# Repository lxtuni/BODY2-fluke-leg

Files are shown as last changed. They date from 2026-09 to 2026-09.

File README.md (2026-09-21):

# BODY2-fluke-leg — Paddling leg for the amphibious quadruped BODY2: fluke-foot design, hydrodynamics and servo trajectory

## Layout

| Folder | Content | Entry point |
|---|---|---|
| `cad/` | One-piece straight fluke foot **A2** (single PETG print: mounting tab → strut → filament-pin hinge + leaf springs → lunate fluke); STL/STEP output, size check, hull cross-section | `fluke_straight_cad.py` generates the part; `直排一体件A2_说明.md` print/assembly notes |
| `firmware/` | Sculling swim trajectory for the motion-control team: `scull_gait_patch.c` (replaces `swim_leg_pose()`), 100-points-per-cycle CSV, servo-angle check | `README_scull.md` |
| `hydro/` | Fluke hydrodynamics: UVLM flapping-foil solver, passive-pitch FSI (phasor method), sculling FSI, E-pivot spade paddle, area/aspect-ratio sweeps | `uvlm_foil.py` (solver) → `passive_pitch.py` / `sculling_fsi.py` |
| `cfd/` | Case generation and post-processing for OpenFOAM overset single-leg / full-robot unsteady CFD (`overPimpleDyMFoam` + `tabulated6DoFMotion`) | `README_cfd.md`, `make_leg_cfd.py`, `paddle_forces.py`, `run_cloud.sh` |
| `gait/` | Optimal-stroke theory for drag-based paddling, fold-timing sweep, structure-independent target trajectory, CFD-matrix post-processing | `optimal_trajectory.py`, `fold_timing_sweep.py`, `gait_to_firmware.py` |
| `docs/` | Research notes 00–14 (chronological, with design decisions), reference list `.bib`, key figures | `docs/notes/00_阅读顺序.md` |

## Current design status (2026-09-20)
- **Mechanism**: leg hangs down, long link stays vertical, the stem swings about the hip axis through **−18° ± 18°** (horizontal at the top of the stroke); the fluke pitches passively on a pin hinge at the stem tip (leaf-spring restoring stiffness k ≈ 2.5 mN·m/rad).
- **Fluke**: lunate planform, AR 3.1, span 60 mm, 11.5 cm², NACA 0021; whole part 98 × 11 × 60 mm, 6.9 g PETG. The 86 mm-span A1 hit the hull bottom at the top of the stroke and was dropped (`docs/figures/fig_size_check.png`).
- **Thrust estimate** (UVLM upper bound × 0.7): ≈ 20 mN per paddle at 1.5 Hz, ≈ 35 mN at 2 Hz. To be measured in the tank.
- **Ballast**: waterline at the hull top; water depth ≥ 15 cm.

## Environment
```bash
pip install -r requirements.txt
# CFD needs OpenFOAM v2606 (WSL2/Ubuntu), see cfd/README_cfd.md
# gait/ post-processing reads local CFD results: export BODY2_CFD_RESULTS=/path/to/leg_dynamics
```

## Reproducing the main results
```bash
python cad/fluke_straight_cad.py          # → cad/fluke_straight_A2.stl/.step + stiffness/strain JSON
python firmware/scull_trajectory.py       # → trajectory CSV + C patch + servo-angle ranges
python hydro/sculling_fsi.py              # sculling FSI sweep (f, θs0, k); takes tens of minutes
python cad/fig_size_check.py              # hull cross-section vs fluke envelope (needs hull_only.step, extracted from the assembly STEP, not tracked)
```

## Not tracked
CFD cases and results (`results_leg/`, `results_verify/`, several GB), animation frames, `.docx/.pdf` reports, SolidWorks sources and the full-robot assembly STEP.

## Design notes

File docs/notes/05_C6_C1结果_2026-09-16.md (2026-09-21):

# 05 · C6 + C1 结果（2026‑09‑16，april 本机 8 核，4 次计算共 3.4 h）

数据：`results_verify/V3c12 V3c06 V3trap`（closed‑only 方案配 V3 的 open）；两态合成第 3 周期；图 `fig_fold_timing_sweep.png`、`results_verify/fig_verify.png`。

| 方案 | 收拢宽 | 速度律 | T / DUTY | F̄x [mN] | 划水 / 回收贡献 | 每周期冲量 [mN·s] | F̄z | \|M_y\| 峰 [mN·m] | P̄ [mW] | F̄x/P̄ |
|---|---|---|---|---|---|---|---|---|---|---|
| V3 | 30 mm | 余弦 | 0.81 / 0.45 | 49.3 | +60.0 / −10.7 | 40.0 | 13.7 | 19.3 | 16.2 | 3.05 |
| V3c12 | 12 mm | 余弦 | 0.81 / 0.45 | **56.7** (+15 %) | +60.0 / −3.2 | 46.0 | 9.9 | 19.3 | 13.7 | 4.13 |
| V3c06 | 5.6 mm（羽化） | 余弦 | 0.81 / 0.45 | 58.6 (+3 % vs c12) | +60.0 / −1.4 | 47.4 | 9.1 | 19.3 | 13.1 | 4.46 |
| V3trap | 12 mm | 梯形 45 ms 斜坡 | 0.72 / 0.382 | **75.0** (+32 % vs c12) | +79.5 / −4.4 | 54.0 (+18 %) | 13.9 | **35.6** | 20.8 | 3.61 |

## 结论
1. **C6 收拢宽度**：30 → 12 mm 使回收阻力从 −10.7 降到 −3.2 mN（÷3.3），周期平均 +15 %，F̄z 也降 28 %。closed‑only 周期平均 21.0 → 4.8 → 1.9 mN。有效阻力比 a（closed/open 周期平均）0.48 → 0.11 → 0.04。
2. **羽化（5.6 mm）只再多 +1.9 mN（+3 %）**。深挖后修正原因：回收阻力其实与宽度成正比（0.70 mN/mm，截距 ≈ 0，杆/附加质量不是地板），但 12 mm 时回收拖累只剩周期平均的 6 %，羽化最多再拿回其中一半。**羽化机构不做**；把收拢宽做到 ≤ 12 mm 即可。
3. **C1 梯形速度律**：划水冲量 48.6 → 57.2 mN·s（+18 %），周期平均 +32 %（含周期缩短 0.81 → 0.72）。深挖后修正解释：同峰值速率、同 50° 摆角下准定常 ∫v² 本来就只多 18 %，CFD 与之一致；有效 C_N（起动 ≈ 5 → 1.5 弦后 2.5–4）在两种速度律下相同，**并没有被恒速段衰减掉**。理论文档的 +60–70 % 隐含“同一划水时间扫 1.33 倍的角”，即要加大摆角/行程 → C2。代价：|M_y| 峰值 19.3 → 35.6 mN·m（×1.84），F_x 峰 277 → 474 mN，P̄ +52 %，F̄x/P̄ 从 4.13 降到 3.61。**目标是最大推力 → 采用梯形**；若舵机峰值力矩 < 40 mN·m 或电源受限，把斜坡放宽到 60–70 ms 折中。
4. **开合时刻（fold_timing_sweep 一维 + deep_dive_optimal 二维）**：二维最优 τ_o −0.06 / τ_c 0.33（V3trap，+16 % → 87.2 mN；V3c12 τ_c 0.37，+12 % → 63.5 mN）。一维结论：三个新方案最优收扇都在 τ_c ≈ 0.86–0.87 × DUTY（V3c12 0.37、V3trap 0.33），即划水减速开始处，与 04 的目标轨迹一致；提前收扇的收益随回收阻力变小反而变大（V3trap +7.5 mN/0.05 T，早收 → 82.7 mN），晚收代价 −4.9 mN/0.05 T。开扇最优 τ_o ≈ −0.06（回收减速起点），+3–6 %。合成上限：V3trap 早收 + 早开 ≈ 85 mN（现 V3 49.3 的 1.7 倍）。

## 对目标轨迹（04）的更新
- 收拢宽度 12 mm、不羽化；DUTY* 按 a = 0.11 重算：x* = √(1+1/a) − 1 = 2.18 → DUTY* = 0.69（准定常极限，说明回收可以更慢；实际取 0.42–0.45 受舵机回收速度限制而不是阻力）。
- 速度律：梯形，v_max 0.35 m/s，斜坡 45 ms（若力矩允许）。
- 收扇 = 划水减速起点，开扇 = 回收减速起点，均不变。

## 深挖产物（2026‑09‑16 下午）
`deep_dive_optimal.py` → `fig_dd_timeseries / unsteady / recovery / timing_map / waterfall.png`、`deep_dive_optimal.json`；`make_optimal_anim.py` → `optimal_gait_cfd_anim.mp4`（放慢 5×，2 周期）+ 分镜；`make_optimal_report.js` → `results/BODY2_最优轨迹报告_2026-09-16.pdf/.docx`（8 页）。最优轨迹定义见报告表 3 / 表 4：V3trap + 收扇 τ 0.33（238 ms，划水减速起点）+ 开扇 τ −0.06（677 ms，回收减速起点）→ F̄x 87.2 mN、冲量 62.8 mN·s、|M_y| 峰 36.7 mN·m、P̄ 21.4 mW。

## 下一步（C2 行程长度）
`ORDER="opt optL63 optL126" NP=8 nohup bash run_cloud.sh > ~/run/run_cloud2.out 2>&1 &`（6 次，约 5–6 h）：决定行程 1.5 / 2 / 3 弦，同时 opt 是整条目标轨迹 vs V3trap 的正面验证。之前须确认舵机峰值力矩 ≥ 40 mN·m（0.4 kg·cm，几乎所有舵机都满足）。

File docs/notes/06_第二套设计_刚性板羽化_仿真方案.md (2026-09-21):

# 06 · 第二套设计：刚性板 + 脚踝羽化关节 —— 仿真方案（2026‑09‑16）

## 0. 设计定义（Design 2）

- 桨板 Paddle：刚性矩形板，厚 5.6 mm，长 42 mm（沿桨杆），宽默认 **44 mm**（等面积 = 18.5 cm²，与第一套 120° 折扇正对面积相同，可直接对比）；变体 73 mm（30.7 cm²，= 折扇最宽处）。
- 脚踝 Knöchel：**主动舵机**，只有两个位置。绕桨杆轴（feathering axis）转 β：划水 β = 0（板面 ⟂ x，正对来流），回程 β = 90°（板面与 x–z 面共面，对面内任何运动都是最小截面 5.6 × 42 = 2.4 cm²，13 %；折扇收拢 12 mm 是 5.0 cm²，27 %）。
- 髋 Hüfte：形式不限，只要求走**结构无关的目标轨迹**（04：直线 84 mm，z = −85 mm，v_max 0.35 m/s，斜坡 45 ms，停顿 30 ms，抬升 30 mm，T 0.684 s，DUTY 0.416）。
- 不再仿真折扇的两态拼接：板绕自身轴的旋转 β(t) 直接写进 6DoF 表（rx ry rz 三个欧拉角），**一次算例含整周期**。

## 1. 生成器改动（make_leg_cfd.py）

```
--fan plate                 # 矩形板（与 open/closed 并列）
--plate-w 0.044             # 板宽 [m]；0.073 = 折扇最宽
--plate-l                   # 板长，默认 HEAD 42 mm
--feather TC,TO,TF[,lin]    # 羽化：收指令相位 τ_c、展开指令相位 τ_o、过渡时间 TF [s]
                            # 缺省余弦斜坡；lin = 匀速（限速舵机）；例 0.351,-0.066,0.11,lin
```
- 6DoF.dat 行：`(t ((tx 0 tz) (rx ry rz)))`，欧拉角 = scipy 'XYZ'（= OpenFOAM `quaternion::XYZ`），已 unwrap。
- 运动包络 (overset 背景加密区) 已按 β 旋转板角点重新计算。
- `kinematics_check.csv` 多出 `beta_deg,rx,ry,rz`；`gait.json` 记录 FEATHER / PLATE_W / PLATE_L。
- 已验证几何：沿桨杆 92 mm；板法向 / 横向尺寸在 β = 0 → 90° 之间 5.6 ↔ 44 mm 互换。

`compare_verify.py` 识别标签 `plate`（模式 `plate_single`，无拼接，直接取第 3 周期均值）。

## 2. 算例表（run_cloud.sh，ORDER 顺序）

| 算例 | 轨迹 | 板宽 | 羽化 (τ_c, τ_o, TF) | 回答的问题 |
|---|---|---|---|---|
| D2a | V3trap（第一套的髋轨迹） | 44 | 0.33, −0.06, 40 ms | 同轨迹、同面积：刚性板+羽化 vs 折扇最优 87.2 mN → 只看"回程截面"的价值 |
| D2b | 04 目标轨迹（直线） | 44 | 0.351, −0.066, 40 ms | 第二套的**基准**：结构无关轨迹 + 快舵机 |
| **D2s** | 04 | 44 | TF 110 ms，匀速 (lin) | **实际舵机 7465W @8.4 V**（0.07 s/60° → 857 °/s，带载 ≈ 820 °/s） |
| D2c100 | 04 | 44 | TF 100 ms（cos） | 舵机 900 °/s 均速的损失 |
| D2c200 | 04 | 44 | TF 200 ms | 舵机 450 °/s（普通 9 g 舵机）的损失 → 选型曲线 |
| D2w73 | 04 | 73 | 40 ms | 面积 +66 % 换推力的代价（功率、侧向力、回程阻力） |
| D2nof | 04 | 44 | 无羽化 | 对照：不转板，回程正对 → 羽化本身的收益 |

预计 NP = 8 每例 55–70 min，七例 ≈ 7–8 h（D2c100 与 D2s 接近，可省）。

`--feather` 第 4 项 `lin` = 匀速斜坡（限速舵机真实形状，峰值速率 = 均速）；缺省 `cos` 的峰值速率是均速的 1.57×，对限速舵机偏乐观。

WSL（在 leg_dynamics 目录）：
```
ORDER="D2b D2s D2nof D2a D2c200 D2w73" NP=8 nohup bash run_cloud.sh > ~/run/run_cloud_d2.out 2>&1 &
tail -f ~/run/run_cloud_d2.out
```

## 3. 预期与判据

- D2b vs 折扇最优 87.2 mN：板正对面积相同，划水段应接近（±10 %，板的 C_N 略高于扇因为无缝隙）；回程阻力应从折扇最优 ≈ −6 mN 降到 ≈ −2 mN → 净推力 ≈ +5 %，主要收益在**回程功率**和横向力，而非净推力。
- D2c100 / D2c200：损失 = 板在划水减速段（τ 0.35–0.42）和回程加速段仍是斜的；预计 100 ms ≈ −3 %，200 ms ≈ −10 %（斜板在 v ≈ 0.2 m/s 下产生升力式侧向力，还会带来 M_y）。
- D2w73：推力上限 ≈ ×1.5，功率 ×1.7，若 F̄z/F̄x 或 |M_y| 明显恶化则不值得。
- D2nof：预期净推力比 D2b 低 30–40 % —— 羽化关节必要性的直接证据。

## 4. 选定舵机：7465W（防水，12 g，金属齿轮，空心杯，180°）

| 电压 | 空载速度 | 堵转力矩 | 空载 / 堵转电流 |
|---|---|---|---|
| 5.0 V | 0.110 s/60° | 3.8 kg·cm | 46 mA / 1.0 A |
| 6.0 V | 0.092 s/60° | 4.5 kg·cm | 53 mA / 1.15 A |
| 7.4 V | 0.075 s/60° | 5.5 kg·cm | 56 mA / 1.4 A |
| **8.4 V** | **0.070 s/60°** | **5.8 kg·cm** | 63 mA / 1.6 A |

按 8.4 V 档：
- 脚踝：857 °/s 空载 → 90° 需 105 ms；羽化水动力矩峰值 ≈ 40 mN·m = 0.4 kg·cm，仅 7 % 堵转 → 速度降 ≈ 7 % → **90° ≈ 110 ms（算例 D2s）**。落在 D2c100 附近，比 40 ms 基准慢 2.7×，预计损失 3–5 %。
- 髋（若同型号，转动关节，杆长 L ≈ 0.12 m）：v_max 0.35 m/s → 167 °/s，仅用到速度的 20 %；峰值水动力矩 ≈ 0.5 N × 0.12 m = 60 mN·m = 0.6 kg·cm（10 % 堵转）+ 板/舵机惯性，余量充足。髋是直线机构则另算。
- 功率（电）：每个舵机运动时 ≈ 8.4 V × (63 mA + 负载电流) ≈ 0.6–1 W，远大于水动力功率 21 mW → 效率由舵机决定，不由水动力决定；四条腿 8 个舵机 ≈ 5–8 W。
- 质量：12 g 在脚踝处（水下有效 ≈ 12 g − 排水 ≈ 4 g 浮力）→ 髋要多承 ~0.1 N 的静力矩，可忽略。

## 4b. 旧估算（保留对照）

- 脚踝：90° 在 40 ms → 2250 °/s（0.027 s/60°）；100 ms → 900 °/s；普通 9 g 舵机 ≈ 500 °/s → 180 ms。力矩峰值 ≈ 40 mN·m = 0.4 kg·cm（任何舵机都够）。**瓶颈是速度**。
- 髋：v_max 0.35 m/s、斜坡 45 ms、峰值横向力 ≈ 0.5 N；若髋是转动关节且杆长 L，则 ψ̇_max = 0.35/L。
- 若买不到 ≥ 1000 °/s 微型舵机：改被动风向标式羽化（自由铰 + 限位），减速段松开靠水流翻转——需要另一组算例（板绕轴的自由转动，6DoF 求解而非表驱动）。

待确认：髋是否同型号 7465W、髋关节形式（转动杆长 / 直线）。

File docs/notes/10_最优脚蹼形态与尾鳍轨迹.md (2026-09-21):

---
title: 10 · 最优脚蹼形态与最佳尾鳍轨迹（UVLM 优化，U = 0.25 m/s）
date: 2026-09-18
status: result
---

# 10 · 最优脚蹼形态与最佳尾鳍轨迹

**问题**：U = 0.25 m/s 巡航，脚蹼面积固定 18.5 cm²，f ≤ 3 Hz，沉浮半幅 h₀ ≤ 50 mm，α_max ≤ 30°；腿做流线型、不考虑舵机。求单桨周期平均推力最大的形态和轨迹。
**方法**：三维非定常涡格法 UVLM（PteraSoftware 5.1），684 次计算（几何 120 + 运动学 564），每次 4–6 s。黏性用 Floryan 2017 式常数偏置 C_D = 0.03。
**产物**：`fig_fluke_optimum.png/.pdf`、`fluke_optimum_anim.mp4`、`fluke_AR4_t0.5_s35.stl`（可打印）、`*_planform_mm.csv`、`*_section_NACA0021.csv`、`sweep_A/B/C.csv`、脚本 `uvlm_foil.py / sweep_fluke.py / fluke_design.py / fig_fluke_optimum.py / make_fluke_opt_anim.py`。

## 一、答案

### 形态（脚部）

| 项 | 取值 | 依据 |
|---|---|---|
| 平面形 | **月牙形（lunate）**：前后缘同时后掠 35°，翼尖弦/展中弦 = 0.5 | 五族平面形里推力最高（比矩形 +3–8%）、效率最高 |
| 展弦比 | **AR 4**（展 86 mm，展中弦 28.7 mm，翼尖弦 14.3 mm） | UVLM 里推力随 AR 单调升（AR 2→6：+47%），但黏性文献（Lagopoulos 2023，Re 8500）C_T 到 AR 4 饱和；再高弦太短、Re 掉 |
| 截面 | **NACA 0021**：t_max 21% @ 0.30c，前缘 R 1.4 mm，尾缘闭合 | Kelly 2023 在 Re 10⁴ 的最优（0.21c @ 0.30c）= 海豚尾鳍实测（0.218c @ 0.285c）；UVLM 不含截面，这一条直接采用文献 |
| 俯仰轴 / 支杆 | **0.30–0.35 c**（展中弦前缘后 8.6–10 mm） | 0.4c 比 0.2c 多 2% 推力，差别小；取 1/3 与文献一致 |
| 支杆 | 流线型截面，尽量短，接在展中 | 见 09 号审查 #4 |

### 轨迹（尾鳍运动）

三条共同结论，对所有 f、h₀ 都成立：

1. **ψ = 90°**（俯仰领先沉浮 1/4 周期）。75° 和 105° 在 St > 0.5 时正弦俯仰压不住攻角上限，且推力低一半。
2. **攻角顶到上限 30°**。α_max 从 20° → 30°，推力 ×2.2。羽化幅值 θ₀ 由 α 上限反解。
3. **推力随 St 单调增长到约 1.0**，之后被 θ₀ 卡住（St 1.2 要 θ₀ = 66°）。

| 工况 | f | h₀ | θ₀ | ψ | St | 推力/桨 | 功率 | η | 俯仰峰速 |
|---|---|---|---|---|---|---|---|---|---|
| **上界（约束盒角）** | 3.0 Hz | 50 mm | 66° | 90° | 1.20 | **346 mN** | 125 mW | 0.69 | 1246 °/s |
| **可信最优（St ≤ 0.8）** | 2.0 Hz | 50 mm | 44° | 90° | 0.80 | **260 mN** | 98 mW | 0.66 | 554 °/s |
| 高效点 | 2.5 Hz | 30 mm | 48° | 90° | 0.60 | 102 mN | 29 mW | 0.87 | 747 °/s |

**推荐用"可信最优"**：St 0.8 已在验证范围（Read 2003 到 St 0.6）附近，无黏上偏可控在 ~20%；St 1.2 的 346 mN 是无失速模型的上界，真实值大概率低得多。

## 二、这个数意味着什么

整机阻力（腿整流后）21–36 mN，四桨只需每桨 **5–9 mN**。可信最优给 260 mN/桨 —— **推力富余 30 倍**。所以：

- U = 0.25 m/s 不是极限，是下限。按推力 ∝ U² 粗算，四桨 1 N 推力对应的自航速度在 0.8–1.2 m/s 量级（受 Re、自由面、舵机三重限制，实际会低）。
- 真正的设计问题不是"够不够推力"，而是**"在推力富余 30 倍的情况下，把 f、h₀ 降到哪里最省电"** —— 那就是高效点那条线（η 0.87，29 mW 出 102 mN，仍是需求的 11 倍）。

## 三、方法与可信度

**验证**（`uvlm_validation.md`）：Schouveiler 2005（Re 4×10⁴，St 0.25，α 15°）：UVLM C_T 0.354 vs 实验 0.32 ± 0.01，η 0.75 vs 0.73 ± 0.04；加 C_D 0.01–0.03 后落进误差棒。Read 2003 最大推力点（St 0.6，α 35°）：C_T 2.96 vs 2.4（**+23%，失速缺失**）。网格/时间步/自由尾迹/周期数敏感性 ≤ 4%。

**不可信的地方**（必须由 LES 复核）：
- α_max = 30° 处推力上偏 ~20%；St > 0.8 的点当上界。
- ψ = 75° 且强羽化的 30 个算例无黏 η > 0.9（功率账不闭合），已剔除。
- St 1.2 的 α 时程呈双峰带缺口（正弦俯仰在大羽化下的固有形状，见视频下图），LEV 会在冲程中间脱落 —— 这正是 09 号里说的"高 St 要做 α 波形整形"，UVLM 看不见这一点。
- 平面形效应 UVLM 只给 3–8%，黏性文献给 15–45%（Van Buren 2017、Fernández-Gutiérrez 2021）；月牙 + 前窄后宽的方向两边一致，量以 LES 为准。
- AR 4 时展中 Re ≈ 7×10³–10⁴，翼尖只有一半；Re 惩罚只用 C_D 0.03 粗算了。

## 四、下一步（按 09 号三层法）

1. LES 复核两个点：可信最优（St 0.8）和高效点（St 0.6），带支杆、NACA 0021、月牙 AR 4 → 校准 UVLM 的 C_D 偏置和 α 上偏。
2. 在 LES 校准后的 UVLM 上做 α 波形整形（方波/前载）扫描 —— St 0.8 处有可能再拿 10–30%。
3. 整机：船体 + 整流腿 RANS 定阻力曲线；两桨串列相位。

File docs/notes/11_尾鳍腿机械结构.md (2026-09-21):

---
title: 11 · 尾鳍腿的机械结构：双连杆可行吗，最优结构是什么
date: 2026-09-18
status: proposal
---

# 11 · 尾鳍腿的机械结构

配套：`mechanism_anim.mp4`（8 s，放慢 2×，含舵机位置）、`fig_mechanism_frame.png`、脚本 `make_mechanism_anim.py`。

## 一、双连杆可不可行 —— 可行，但第二连杆必须是脚蹼本身

尾鳍轨迹需要两个独立量：**位置（沉浮）** 和 **姿态（俯仰，且领先 90°）**。

| 结构 | 自由度 | 能否做尾鳍轨迹 |
|---|---|---|
| 髋 + 膝（两个位置自由度，脚蹼固连在小腿上） | 2 | **不能**。位置定了姿态就定了，做不出"位置和姿态各走各的正弦、相差 90°" |
| 髋 + 脚蹼俯仰（摇臂 + 攻角） | 2 | **能**。沉浮走弧线而不是直线，但这没关系（下） |
| 髋 + 膝 + 脚蹼俯仰 | 3 | 能，且能走直线沉浮 —— 但多出来的膝没有收益 |

**膝关节没有必要 —— UVLM 算过**：腿长 110 mm 的摇臂弧线沉浮（髋摆 ±27°，附带 ±6 mm 的 2 倍频纵荡）与理想直线沉浮相比：

| | 推力 | 功率（含纵荡做功） | η |
|---|---|---|---|
| 直线沉浮 | 259 mN | 98.7 mW | 0.656 |
| 摇臂 L = 110 mm | 280 mN | 107.9 mW | 0.648 |

推力 +8%、功率 +9%、效率不变。腿越短纵荡越大（L = 80 mm：+13%），都是二阶量。**所以答案：两个舵机就够 —— 一个摆腿，一个转脚蹼。**

## 二、两种布置

### 方案 F（推荐）鱼尾式：腿竖直、横向摆，脚蹼竖放

- **S1 髋滚转舵机**：在船侧，轴沿 x（前后向），把竖直的流线腿横向摆 ±27° → 脚蹼横向沉浮 ±50 mm。
- **S2 扭转舵机**：装在髋支架上（随腿摆），输出轴沿腿，通过腿内扭转轴让脚蹼绕腿轴转 ±44° → 俯仰。S2 的角度就是脚蹼的绝对俯仰角，和 S1 完全解耦。
- 脚蹼竖放（展向 z），装在腿末端展中，深度恒定（顶端 ≈ 水线下 55 mm，d/c ≈ 2 → 自由面效应可忽略）。
- 腿是竖直支柱，只在脚蹼展中与它交汇（结合部流 junction flow），不在前缘上游 —— 09 号里"支杆尾迹打到前缘"的问题在这个布置里不存在。
- 左右腿镜像反相：侧向力抵消、偏航力矩抵消。

### 方案 D 海豚式：腿向后拖、上下摆，脚蹼平放

- 髋要放深（脚蹼顶端离水面 ≥ 1.5 弦），所以船底先出一根**固定流线支柱**，髋在支柱底部；S1 在船体内，经支柱内轴驱动。
- **S1 髋俯仰舵机**（轴沿 y）上下摆向后拖的腿 ±27°，腿平均下倾 15°。
- **S2 俯仰舵机**在船体内，经**平行四边形连杆**把绝对俯仰角传到脚蹼（与髋摆角无关）—— 这就是 BODY2 现有"ψ 摇臂 + φ 平行四边形"结构换个姿势。
- 缺点：脚蹼在冲程顶端离水面近（自由面损失）；四腿的垂向力要靠对角步态（trot）才能把纵摇和横摇都抵消；腿在冲程底部离船远、顶部贴船底。

### 为什么推荐 F

| | F 鱼尾式 | D 海豚式 |
|---|---|---|
| 脚蹼深度 | 恒定，d/c ≈ 2 | 随冲程变化，顶端 d/c ≈ 1 |
| 支杆干扰 | 结合部流（小） | 支柱 + 腿都在流场里，腿贴船底 |
| 力的抵消 | 左右反相即可 | 需对角步态 |
| 舵机位置 | S1 船内；S2 在髋部随腿摆（需密封小舱或防水舵机） | 两个都在船内（干） |
| 与现有 BODY2 结构的关系 | 髋轴要从 y 改成 x | 保留 ψ/φ 平行四边形，加一根固定支柱 |

F 的唯一代价是 S2 要跟着腿摆（或用腿内扭转轴 + 船内舵机 + 一个万向节）。

## 三、还没定的两件事

1. **S2 的位置**：F 方案里 S2 装在髋部随腿摆最简单，但要密封；也可以把 S2 放船内，扭转轴通过一个万向节（或柔性轴）穿过髋滚转轴 —— 这是纯机械问题。
2. **行走**：两种方案都只有一个髋自由度，走路要再加一个（F 加 y 轴髋摆，D 加 x 轴外展）。按你说的，工程先不管。

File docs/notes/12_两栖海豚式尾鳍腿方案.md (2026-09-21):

---
title: 12 · 两栖海豚式尾鳍腿方案（髋 + 膝 + 脚蹼俯仰，3 舵机）
date: 2026-09-18
status: proposal
---

# 12 · 两栖海豚式尾鳍腿方案

配套：`amphib_leg_anim.mp4`（10 s，放慢 2×：游泳 / 行走 / 整机三视图 + 舵机指令曲线）、脚本 `make_amphib_leg_anim.py`。替代 11 号里的方案 F（鱼尾式），原因：机器人核心是两栖，腿必须能向下站立，所以髋轴保持 y 轴（矢状面），沉浮方向取竖直 —— 海豚式。

## 一、结构：三个舵机，全部 y 轴，全在矢状面

| 舵机 | 位置 | 游泳时 | 行走时 |
|---|---|---|---|
| **S1 髋** | 船内 | **固定**：把大腿转成向后下 30° 的流线支柱，把膝放到水线下 ≈ 100 mm | 摆动 ±25°，标准步态 |
| **S2 膝** | 船内，经平行四边形下传（= 现有 BODY2 的 φ 机构） | **上下摆 ±27°**：小腿向后拖、平均下倾 10° → 脚蹼沉浮 ±50 mm | 折/伸，抬腿 |
| **S3 脚蹼俯仰** | 膝部，推杆走小腿内部到脚蹼曲柄 | 绝对俯仰 ±44°、领先沉浮 90°（指令 = θ − 小腿角） | 把脚蹼放平当脚掌 |

尺寸：大腿 90 mm、小腿 110 mm、脚蹼弦 28.7 mm（月牙 AR 4，NACA 0021，见 10 号）。

**为什么用膝而不是髋来拍**：髋在水线下只有 12 mm，直接用髋摆腿的话冲程顶端会露出水面。大腿当"支柱"把膝放深 100 mm 后，小腿拍动的最高点离水面 ≈ 58 mm = 2.0 弦，自由面效应可以忽略（Cleaver 2013：d/c > 2）。这就是 11 号里那根"固定流线支柱"—— 现在它就是大腿本身，不需要额外零件。

**为什么不需要第四个自由度**：摇臂弧线沉浮（小腿 110 mm，附带 ±6 mm 二倍频纵荡）与直线沉浮相比 UVLM 推力 +8%、η 不变（11 号）。髋不参与拍动，只负责模式切换和深度微调。

## 二、模式切换

游泳 → 行走：髋从"向后下 30°"转到"向前下 ~30°"（约 60°），膝从 100° 张角折到步态角，S3 把脚蹼从俯仰位转到水平。**不换零件，三个舵机各转一次。** 脚蹼当脚掌时前缘朝前、尾缘着地 —— 尖尾缘要加一条胶条（工程细节）。

## 三、整机相位

四条腿的垂向力要抵消：同侧前后腿反相、左右镜像 → 对角两腿同相（trot 型）。净垂向力、纵摇、横摇三项都为零（推导：F_fl + F_fr + F_rl + F_rr = 0 且两个力矩为零 ⇔ 对角同相）。

前腿脚蹼落在后腿前方约 5 弦：后腿在前腿尾迹里工作，推力可在 0–2× 之间摆（Muscutt 2017），最优相位随速度线性移动 —— 前后相位差要做成可调，不能固定 180°。这是第 3 层 LES（两桨串列）要回答的。

## 四、支杆干扰的位置变了

小腿从前上方 10–35° 斜着接到脚蹼俯仰轴（0.33c），不在前缘正上游。是"斜支柱 + 结合部流"，比 09 号里假设的"50 mm 圆杆在前缘上游"轻得多，但 LES 仍然要带着小腿算。小腿截面做成流线型（NACA 0020 类，弦 ≈ 12 mm）。

## 五、与 BODY2 现有结构的关系

现有 = ψ 摇臂（髋）+ φ 平行四边形（控制桨板角）= 本方案的 S1 + S2。**只需新增 S3（脚蹼俯仰）和把折扇桨换成月牙脚蹼。** 起步/机动仍可用阻力型划水（你之前定的），那时 S3 把脚蹼转到垂直迎流，就是一块 18.5 cm² 的桨板。

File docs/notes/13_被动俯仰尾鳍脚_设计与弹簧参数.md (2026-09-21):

---
title: 13 · 被动俯仰尾鳍脚：完整设计与弹簧参数（只换脚，不换舵机）
date: 2026-09-18
status: design
---

# 13 · 被动俯仰尾鳍脚：完整设计与弹簧参数

配套：`fig_passive_foot_design.png/.pdf`（六视图设计图）、`passive_pitch.py`（UVLM 流固耦合求解）、`passive_pitch_sweep.json`（126 个工况）、`passive_foot_design.json`（设计点）、`fluke_AR4_t0.5_s35.stl`（翼）。

## 一、思路

现有腿 = 髋摇臂 ψ + 平行四边形 φ，桨轴与摇臂平行。把摇臂固定在 **ψ = 90°（竖直向下）**，平行四边形 φ 让桨根 E 在半径 39 mm 的**竖直半圆**上平移——**上下 ±30 mm、不转动**。这就是尾鳍要的沉浮。俯仰不用第三个舵机：翼装在支杆末端的**扭簧铰**上，水动力矩让它风向标式地转向相对来流，弹簧决定转多少。

## 二、设计参数

### 运动（舵机指令）

| 量 | 值 |
|---|---|
| ψ（髋摇臂） | 固定 90°；只用于调深度 |
| φ（平行四边形） | φ(t) = 90° + asin(h(t)/39 mm)，h = h₀ sin ωt |
| h₀ | 30 mm（φ 40°–140°） |
| f | 巡航 1.5 Hz，冲刺 2 Hz |
| φ 峰值角速度 | 415 °/s（1.5 Hz）/ 554 °/s（2 Hz）；7465W 820 °/s → 余量 2.0× / 1.5× |
| 附带纵荡 | ±7 mm，二倍频（半圆轨迹固有；UVLM 算过：推力 +8%，η 不变） |

### 脚（打印件，约 5 g）

| 量 | 值 |
|---|---|
| 平面形 | 月牙 AR 4：展 86、展中弦 28.7、翼尖弦 14.3、前后缘后掠 35°、S 18.5 cm² |
| 截面 | NACA 0021（t_max 6.0 mm @ 0.30 c，前缘 R 1.4 mm，尾缘尖） |
| 铰轴位置 x_p | **9 mm**（展中前缘之后，0.31 c）；气动中心 AC 在 18.6 mm（UVLM 识别，后掠平面形的 AC 比 1/4 弦靠后）→ 铰在 AC 之前 9.6 mm，静稳定 |
| 铰 | Ø2 mm 不锈钢针，PTFE/POM 衬套，沿展向穿过展中 |
| 支杆 | E → 铰轴 **105 mm**，截面改成流线 4×8 mm；沿自身轴上下运动，阻力≈0；穿越水面 |
| 深度 | 铰轴中心水线下 76 mm；冲程顶端翼离水面 46 mm ≈ 1.6 弦（可再加长 10 mm 到 2 弦） |
| 限位 | ±45°（把 α 时程削成平台型） |
| 中立 | θ = 0（弦垂直于支杆），预紧 0 |

### 弹簧与阻尼

**目标 k = 3 mN·m/rad = 0.052 mN·m/°**（f 1.5 Hz 时 χ = K_f/(k+K_f) ≈ 0.48）

| 方案 | 规格 |
|---|---|
| 琴钢丝扭簧（E 200 GPa，k = E d⁴/(64 D N)） | d 0.35 · D 5 · 3 圈 ／ d 0.39 · D 6 · 4 圈 ／ d 0.44 · D 8 · 5 圈。双向：两只对置，或一只预压在中立位 |
| **TPU 95A 柔性铰（推荐先试）** | 宽 20 × 厚 1.0 × 长 8 mm → k ≈ 6 mN·m/rad；厚 0.8 → ≈ 3；直接打印在翼上，无零件 |
| PETG 柔性铰 | 宽 20 × 厚 0.35 × 长 8 → 18 mN·m/rad，太硬，只作对照 |
| 阻尼 | **c ≥ 0.10–0.15 mN·m·s/rad**。UVLM 识别的流体阻尼在 x_p ≤ 9 mm 时为**负**（−0.05…−0.09）：无结构阻尼会自激颤振。铰轴硅脂 + 0.1 mm 轴向间隙，台架上调到不颤为止 |

刚度扫描的规律（图 D/E）：k 从 1 → 14 mN·m/rad，θ₀ 从 30° 降到 11°，相位 64° → 78°，α_max 从 29° 升到 38°，推力 66 → 73 mN（1.5 Hz）。**k 在 2–4 之间都行**，α_max 落在 27–31°；越软越省功（η 高），越硬推力略大。

## 三、预期性能（UVLM 流固耦合，基波相量法，含 C_D 0.03）

| 工况 | θ₀ | 相位 ψ | α_max | 推力/桨 | 沉浮功率 | 备注 |
|---|---|---|---|---|---|---|
| **巡航 1.5 Hz** | ±23° | 69° | 30° | **69 mN** | 21 mW | 主动最优同工况 ≈ 60 mN → 被动 ≈ 100% |
| 冲刺 2 Hz | ±27° | 71° | 35° | ≤ 128 mN | 42 mW | α 超 30°，真实会部分失速，打折 |
| 对比：现在划水（V3trap 最优） | — | — | — | 87 mN | ~21 mW（舵机功） | 回程在水里 |

整机需求 21–36 mN（腿整流后）→ 四桨 276 mN，富余 8 倍；0.25 m/s 是下限。

## 四、可信度与要验证的

- 相位 69° 而非 90°：结构惯量 + 负流体阻尼的滞后；文献上 70–80° 仍在高效区。
- UVLM 无失速：α_max 30° 边缘，2 Hz 工况 35° 必然部分失速。绝对推力上偏 ~20%。
- 低 k（≤ 2）时基波法残差 0.3–0.7（非线性、大角度），数值粗；k ≥ 3 残差 < 0.2。
- 负流体阻尼是这套设计最需要台架验证的一点：**先把翼装在支杆上放进水流（或拖）看它颤不颤**，再装机器人。
- 连杆尺寸按 `leg_dynamics.py` 的 CAD 值（平行四边形 39 mm）。照片上的腿明显更长（长杆约 90 mm）：规律不变，h₀ = L_PAR·sin Δφ，杆越长同样沉浮需要的 φ 摆角和舵机角速度越小。**用实际杆长重新代一遍数再打印。**

## 五、一条要改正的旧记录

10 号笔记里"俯仰轴 0.30–0.35 c"是错的：`uvlm_foil.run_case` 的 pivot 参数是"展中前缘之后的距离 / 翼尖弦（14.3 mm）"，所以当时扫的 0.2/0.3/0.4 实际是展中前缘后 2.9/4.3/5.7 mm = **0.10/0.15/0.20 c**，都在气动中心（0.65 c）之前。结论"轴靠后一点推力略大"不变，但数值要按这个口径读。本文件的 x_p 直接用 mm。

## 六、装配顺序

1. 打印翼（STL）+ TPU 柔性铰版本两个厚度（0.8、1.0 mm）。
2. 支杆换流线截面、加长到 105 mm，末端做铰座和 ±45° 限位。
3. 台架：翼 + 支杆固定在拖车/水槽里，0.25 m/s 来流，手动上下抽动 → 看被动俯仰是否跟随、有无颤振。
4. 装机器人一条腿，系留测推力（弹簧秤或力传感器），扫 k（换铰厚度）和 f。
5. 四腿，对角相位，自由航行测速度、电流。

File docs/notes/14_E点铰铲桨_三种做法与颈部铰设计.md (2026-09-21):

---
title: 14 · 现有铲形桨 + 平行四边形末端 E 铰：能不能做成升力型？
date: 2026-09-18
status: design
---

# 14 · 现有铲形桨 + E 点铰：三种做法的流固耦合结果与颈部铰设计

配套：`fig_paddle_E_design.png/.pdf`（六图）、`paddle_E_anim.mp4`（一个周期，放慢 3×）、脚本 `pendulum_paddle.py`（整桨绕 E 被动）、`paddle_active_E.py`（绕 E 主动俯仰）、`passive_spade.py`（颈部铰被动）、`pendulum_traj.py`（ψ+φ 逆解）、`fig_paddle_E_design.py`、`make_paddle_E_anim.py`；数据 `pendulum_paddle_sweep.json`（72）、`paddle_active_E_A.json`（200）、`paddle_active_E_bigh0.json`（9）、`passive_spade_sweep.json`（60）、`paddle_E_design.json`。

## 一、你画的方案（整根桨绕蓝点 E 被动摆、红扇区）——算过了，不行

模型：铲头按 CAD 44 × 42 mm 鱼尾平面形（12.9 cm²，UVLM 升力面），杆长 L_stem 30 / 50 / 82 mm（CAD 50、照片 ≈ 82），铰在 E，扭簧 k 0–50 mN·m/rad，阻尼 0.3 / 1.0 mN·m·s/rad，E 沉浮 ±20 mm（现有连杆能走直线的极限），1.5 / 2 Hz。桨（杆 + 头）质量 12 g。

结果（图 B）：

| 弹簧 | 1.5 Hz 推力/桨 | 2 Hz |
|---|---|---|
| 无簧 / 软簧（k ≤ 6） | **−2 … +4 mN**（负 = 阻力） | −1.6 … +8 |
| 硬簧 k 25–50 | 8–12 mN | 20–24 |
| 参考：刚性板纯沉浮 h0 20 | 11.6 | 21.8 |

**任何弹簧都不超过把桨焊死做纯沉浮。** 原因不是弹簧选错，是几何：铰离桨头 70–100 mm，桨头的沉浮 = E 沉浮 + r·θ，被"俯仰"带动的头部沉浮反过来给铰轴一个巨大的流体阻尼力矩（识别值 C_f 1.2–7 mN·m·s/rad，是 13 号翼根铰的 30–70 倍）。方程 Θ = M_h/(k − Iω² + icω − A) 的分母被阻尼项统治，**俯仰滞后沉浮 70–90°**，而升力型需要领先 90°。桨随水流甩，攻角 50–70°，就是一块拍水的板。判据：ωr/U = 9.4 × 0.07 / 0.25 ≈ 2.6 ≫ 1，风向标式的准静态跟随不成立；13 号设计 r ≈ 10 mm，ωr/U ≈ 0.4，才成立。

另外红扇区画在"前伸水平 → 竖直向下"：升力型要求桨头绕**来流方向（水平）对称摆 ±20°**，平均攻角为零；扇区如果以竖直为中心，平均攻角 −90°，那是阻力桨。

## 二、改进版：铰仍在 E，用 ψ 舵机经硬簧主动俯仰——可行但没意义

把弹簧做硬（≈100 mN·m/rad，串联弹性），俯仰相位由 ψ 舵机给。UVLM 扫 θ0 10–30°、相位 60–180°、h0 15/20、杆 50/82（图 C）：

- 攻角 ≤ 30°（不失速）内最大 **10 mN/桨**，≤ 36° 内 **17–20 mN**，η 0.45–0.5。
- 原因同上：远铰把头部沉浮和俯仰锁成同相，要恢复"俯仰领先 90°"只能让 E 沉浮抵消一部分俯仰诱导沉浮，头部有效沉浮反而变小（相量：需要 cos ψ = −rθ0/h0，头部幅值 = h0·sin ψ）。E 沉浮 ±35–40 mm 时能到 20–29 mN，但现有连杆到不了那么深。
- α 60–75° 的点算出 80–200 mN，是 UVLM 无失速的假象，真实是阻力型拍水，效率 ~0.25。

## 三、推荐：弹簧铰移到铲头颈部，头朝后拖，E 接一个下折颈件

**只改"桨与连杆之间的连接件"，铲头形状不变**——符合你的范围，但铰轴不在 E，在铲头的窄颈。

### 结构（图 A）

| 件 | 说明 |
|---|---|
| ψ 舵机（髋） | 固定 **−90°**（摇臂竖直向下），只用来定深度。要确认摇臂能被曲柄–连杆转到这个角。 |
| φ 舵机 | **φ = 90° ± 30°**，E 在以 C 为圆心、半径 L_PAR 的圆弧上走，切线竖直：h0 = L_PAR·sin30° = 30 mm（按照片估计 L_PAR 60；CAD 39 只有 19.5），二阶纵荡 ±4 mm |
| 颈件（新打印，PETG） | 装在 E（原来杆的位置），**下折 45 mm** 再向后 40 mm 到铰座；截面流线 6 × 12 mm |
| 铰 | Ø2 不锈钢销，横向穿过铲头窄颈，**在尖端之后 5 mm**；POM/PTFE 衬套 |
| 扭簧 | **k = 3 mN·m/rad = 0.052 mN·m/°**（k 2–5 都行）；琴钢丝 d 0.35 · D 5 · 3 圈，或 TPU 95A 柔性铰 20 × 0.8 × 8 mm ≈ 3 |
| 阻尼 | 不要求。这个几何的流体阻尼为正（C_f +0.18 … +0.40 mN·m·s/rad），不会自激；13 号翼根铰的负阻尼问题这里没有 |
| 限位 | ±40°（工作 ±19–25°） |
| 预紧 | 铲头水中净重 ≈ 15 mN，质心在铰后 25 mm → 0.4 mN·m，k 3 时下垂 7°；中立位预抬 7°，或头背贴 1 cm³ 泡沫 |
| 深度 | 铰轴心水线下 71 mm；冲程顶端头离水面 ≈ 27 mm（0.65 弦，自由面还有一点损失，可把下折加到 60） |

### 性能（UVLM 流固耦合，基波相量法，铲头 12.9 cm²，含 C_D 0.05）

| 工况 | θ0 | 相位 | χ | α_max | 推力/桨 | 功率 | η |
|---|---|---|---|---|---|---|---|
| **1.5 Hz，h0 30，k 3** | ±19° | 83° | 0.39 | 30° | **26 mN** | 11 mW | 0.60 |
| 2 Hz，h0 30，k 3 | ±25° | 83° | 0.45 | 32° | **47 mN** | 19 mW | 0.61 |
| 1.5 Hz，h0 20（CAD 杆长） | ±13° | 86° | — | 24° | 10 mN | 4.6 mW | 0.55 |
| 2 Hz，h0 30，k 1（最省功） | ±32° | 70° | 0.57 | 33° | 39 mN | 12.5 mW | 0.79 |

k 从 1 → 8：θ0 32° → 11°，推力 21 → 29 mN（1.5 Hz），η 0.75 → 0.49。软簧省功、硬簧推力略大，k 3 是 α ≤ 30° 的边界。

四桨 104 mN（1.5 Hz）/ 186 mN（2 Hz）。整机需求：腿整流后 21–36 mN，不整流 ≈ 100 mN → **2 Hz 时不整流也够，1.5 Hz 要整流**。照片上的铲头比 CAD 大（≈ 64 × 50），面积约 2.3 倍，推力大致按面积放大 → 50–100 mN/桨。

### 对比（图 F，同一铲头、1.5 Hz）

| 做法 | 推力/桨 | 功率 |
|---|---|---|
| 现在：阻力划水（4 号 V3trap 最优） | 87 mN | ~21 mW（舵机） |
| 你的概念：整桨绕 E 被动 | ≤ 12 mN，软簧为负 | 7 mW |
| 铰在 E，ψ 主动经硬簧，α ≤ 36° | 20 mN | 11 mW |
| **颈部扭簧铰，h0 30** | **26 mN（2 Hz 47）** | 11 mW |
| 13 号月牙脚（18.5 cm² NACA0021，h0 30） | 69 mN | 21 mW |

铲头方案推力是月牙脚的 40%：面积小 30%、平板无截面、展弦比 1.5。升力型在这台机器上要真正压过阻力划水，还是得换 10 号的脚。

## 四、动画里看什么

`paddle_E_anim.mp4`：ψ 不动，只有 φ 在 60–120° 之间摆；E 上下 ±30；铲头绕颈部铰被动转 ±19°，领先沉浮 83°；相对来流矢量与攻角实时显示（峰 30°）。

## 五、假设与要验证的

1. **连杆尺寸是照片估计（摇臂短端 40、长边 60）**，CAD 是 14.7 / 39。用 CAD 尺寸 h0 只有 19.5 mm，推力 10 mN。请量实物：O2→C、O2→D（= C→E）、铲头长宽。
2. 摇臂能否转到竖直向下（ψ = −90°）：按 CAD 的曲柄–连杆（O1、28、35、30.1）可以，实物要试。
3. E 在冲程顶端出水 4 mm（h0 30 时），连杆在水面附近上下拍——可接受，或 h0 取 25。两根长杆浸水段垂直运动的阻力 ≈ 30 mN 峰值、~2 mW，做成椭圆截面可减半。
4. 行走：头朝后时脚是"L"形，站立时铲头被地面顶到 +40° 限位。要么把上限位改成 +25°（不影响游泳 ±19°），要么接受重新规划步态。铲头朝前当脚的原状态和升力型游泳不能同时满足，除非颈件做成两个安装角（手动换）。
5. UVLM 无失速：2 Hz 工况 α 32°，真实推力打 10–20% 折扣。平板厚 5.6 mm 方边，前缘分离比 NACA 截面早——把铲头前缘（窄颈那端）打磨成圆角。
6. 基波法残差 < 0.02（k ≥ 2），可信；k 1 残差 0.06–0.2。

## 六、下一步

- 量尺寸 → 重跑 `passive_spade.py`（改 R_PAR / 头尺寸）→ 打印颈件 + 切下铲头装铰。
- 台架：单腿系留，1.5 / 2 Hz，弹簧秤测推力；换 TPU 铰厚度扫 k。
- 若推力确认在 20–50 mN/桨，再决定是否换 10 号月牙脚（同一颈件、同一铰，只换头）。

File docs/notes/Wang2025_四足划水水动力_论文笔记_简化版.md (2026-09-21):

---
type: paper
title: A Computational Study on the Hydrodynamics of Bio-Inspired Quadrupedal Paddling（简化版笔记）
institute: 华南理工大学 吴贤铭智能工程学院 (Shien-Ming Wu School of Intelligent Engineering, SCUT)；合作 北京大学力学与工程科学系
year: 2025
venue: Biomimetics 10(3), 148
paper_type: journal
doi: 10.3390/biomimetics10030148
status: read
topics:
  - 四足划水 quadrupedal paddling
  - 阻力型推进 drag-based thrust
  - 步态序列 gait sequence
Annotator: Lu (Xiaotian Lu)
date_created: 2026-09-17
---

# 四足划水的水动力学（简化版笔记）

## 一句话结论

四条腿一起划，比四条腿各划各的更划算——**腿间干涉 (inter-limb interaction) 是增益**，多出 10–40% 推力 (thrust)；而把划水段 (power phase) 缩短确实能大幅提推力，但力矩 (hydrodynamic moments) 和能耗 (energy expenditure) 涨得比推力还快。

## 研究问题

一台机器狗在水里划水，作者问三件事：

1. 腿摆到哪个角度（**初始摆角 initial swing angle α₀**）、摆多大（**摆幅 swing amplitude β₀**）、划水占一个周期的多少比例（**划水相占空比 power phase ratio DR**），对推力有什么影响？
2. 四条腿按什么顺序划（**步态序列 gait sequence**，三种），有什么影响？
3. 这些选择会让机体多晃（**水动力矩 hydrodynamic moments** Mx/My/Mz）、多费电（**能耗 energetics**）多少？

## 工作缺口

以前算四足划水，基本都是套一个阻力公式 (drag equation) 再假设一个阻力系数 Cd，腿的三维形状和腿与腿之间的相互影响全被忽略。作者原话是这类简化模型 *"easy to use but may lead to significant errors in practice"*。

已有的桨腿 CFD 算的是小龙虾 (crawfish)、海狸 (beaver)、海龟 (turtle)，形态跟哺乳动物式划水差很远。**四条腿的划水顺序 (gait sequence)** 这个维度，此前没有人用 CFD 算过——这是本文自我定位的核心空白。

## 核心贡献

把 α₀、β₀、DR 各取三个值，再乘三种步态，全算了一遍，得到三件事：

**第一，给三种推力生成机制起了名字。**

- **Trotting Mode（对角小跑模式）**：对角两腿 (diagonal legs) 同时划，一个周期里两个推力峰；一对腿出力时被另一对腿削弱。
- **Hindering Mode（干扰模式）**：四条腿依次划，但每条腿出力时会被**前一条腿离开划水相、进入回程 (recovery phase)** 产生的诱导阻力"咬掉一口"，峰顶呈 M 形。
- **Separate Mode（分离模式）**：划水段更短时，四条腿彻底错开，四个干净的推力峰均匀分布，互不打扰。

**第二，证明了腿间干涉是好事。** 用 **F̄x / 4F̄SL**（四腿平均推力 ÷ 四倍单腿 single leg, SL 推力）这个比值衡量，结果是 1.00–1.87，也就是四腿总推力比"四倍单腿"高 10–87%。

**第三，给出了代价。** 推力越大，横摇 (rolling Mx)、纵摇 (pitching My)、偏航 (yawing Mz) 越厉害，耗电越多，而且耗电涨得更快。

## 方法

**几何与运动学。** 一台真机器狗的尺寸：大腿 (upper limb) L₁ = 10.6 cm、小腿 (lower limb) L₂ = 12.0 cm、肢宽 (limb width) W = 4.65 cm，前后腿距 32 cm、左右距 12.4 cm。四条腿记作 LF / LH / RF / RH（左前、左后、右前、右后）。

腿当成**刚性 (rigid)、无变形、无脚蹼**的杆——划水和收腿时迎水面积完全一样。机体**系留 (tethered)** 不动、无来流 (U = 0)，采用**单向耦合 (one-way coupling)**：腿搅动水，但水不让腿变形。腿的摆动角 α(t)、γ(t) 是从真狗游泳的视频里重建出来的。

**参数。** α₀ ∈ {60°, 70°, 80°}，β₀ ∈ {20°, 30°, 40°}，DR ∈ {50%, 33%, 25%}。周期 T 只由 β₀ 决定（0.8 / 1.2 / 1.6 s），**DR 变小 = 在同一周期里把划水段压得更短更快**：小腿端平均速度 (average lower limb tip velocity) Ū 从 0.42 一路涨到 1.34 m/s。

**数值方法。** 自研的**尖锐界面浸没边界法 (sharp-interface immersed-boundary method, IBM)**，笛卡尔网格 (Cartesian grid) 290 × 160 × 160，加密区 Δx = 0.25 cm，Δt = 2 × 10⁻⁴ s，每条腿表面 29 940 个三角元。峰值雷诺数 Re 达 6 × 10⁴ 但**按层流处理，不用湍流模型**。域分解 (domain decomposition) 256 个子域、256 核。取第 5 个周期的结果。附录 A 做了**网格无关性 (mesh independency)** 和**时间步无关性 (time step independency)** 验证。

**一个读表必备的换算：** 论文里的力都是无量纲的（除以 ρ U₀² W²，U₀ = 0.42 m/s），**乘 0.381 就是牛顿**。

## 最强证据

**表 3 (Table 3)，即 F̄x / 4F̄SL 那张表。**

它把"四腿总推力 ÷ 四倍单腿推力"列了 27 个组合，几乎全大于 1，最高 **1.87**（α₀ 80°、β₀ 20°、DR 25%），只有一个组合等于 1.00。

这张表一次证明两件事：腿之间互相帮忙而不是互相拖累；而且这个帮忙**没规律**——同样把 DR 从 33% 压到 25%，(80°, 20°) 从 1.52 涨到 1.87，(60°, 20°) 却从 1.20 掉回 1.00。所以作者说，四足划水的水动力 *"is not necessarily a simple linear superposition with phase shift of those from single-leg paddling"*。

**顺带解释一个容易绕晕的地方：** 为什么分母是 4 倍而不是 2 倍（明明同时只有两条腿在推）？因为分母里的 F̄SL 是**单腿在一整个周期里的平均值 (cycle average)**，那条腿也只有 DR 那段时间在推、其余时间在拖阻力，这个折扣已经算进去了。四条腿错开相位，只改变波形形状，不改变平均值。"只有一半"的直觉对应的是**瞬时峰值 (peak thrust F̄x,pk)**——那里确实是 2 倍：四腿峰值 20.95 vs 单腿峰值 10.53。

## 对比与消融

**Baseline：** 单腿划水 (single-leg paddling, SL)。每张四腿力曲线图上都叠了对应的单腿曲线做对照，F̄x / 4F̄SL 这个指标才得以定义。

**Ablation：** α₀ × β₀ × DR 各三个值（3 × 3 × 3），乘三种步态；输出力、力矩、功率三套。

**被单独验证的因素：**

- 功率 P(t) 跟初始摆角 α₀ **完全无关**（图 11a,b 三条曲线重合成一条）。而减小 α₀ 能提推力 → **α₀ 是"白拿"的参数**。
- 对角序 (diagonal sequence) 和同侧序 (lateral sequence) 两种步态**功率曲线完全重合**、推力几乎一样，只差 T/4 相位 → 选哪个都行。
- 网格与时间步无关性（附录 A）。

## 局限与疑问

**最大的问题：DR 的收益其实是桨速 (paddle velocity) 的收益。** DR 从 50% 压到 25% 时，Ū 从 0.42 涨到 1.34 m/s。推力 ∝ v²，涨是必然的。用论文自己按 Ū² 归一的**推力系数 (thrust coefficient) CT** 看，反而是 0.24 → 0.19 → 0.18 一路下降。这个数在表 2 里，作者没讨论。

**能耗代价被轻描淡写。** 同一组 (α₀ = 80°, β₀ = 40°)：推力 1.90 → 2.89 → 4.49（×2.36），而单周期做功 (work per cycle) 1.37 → 2.40 → 4.37 J（×3.19）——**每焦耳换来的推力掉了 26%**。论文只写了一句 *"additional energy expenditure becomes inevitable"*，全文没有任何效率指标（没有 Froude efficiency、没有推力–功率曲线），所以"最优 DR 到底是多少"这个最值钱的问题并没有被回答。

**没有任何实验校核 (experimental validation)。** 换算成牛顿，它算出的单腿推力是 0.29–0.90 N，而 Qu 2025 对真实机器狗的实测是 0.12–0.17 N，高了 2–5 倍。机器不同不能直接判谁对，但纯 CFD 不做标定还是要警惕。

**M 形缺口的解释有替代可能。** 作者说是前一条腿进入回程 (recovery phase) 造成的诱导阻力，但同一时刻也正是当前这条腿自己尾涡脱落 (vortex shedding) 的时刻。论文用的是压力云图 (pressure contour) 的定性观察，没做"去掉前一条腿"的对照算例，两种解释区分不了。

**最关键的隐含假设：收腿和划水的迎流面积完全相同。** 全文所有"回程是负贡献"的结论都建在这上面。

## 与我的研究的关系

### 已经被它做掉的

- **步态序列不用我再算了。** 结论直接拿来用：要稳就 trot（Mx、Mz 显著更小），要推力就序列步态 (sequence gait) + 小 DR。
- **腿间干涉是正的**（F̄x / 4F̄SL ≥ 1），所以我"先优化单腿轨迹、再考虑整机"的路线站得住——整机耦合是个 1.0–1.9 的加分系数，不是扣分项。
- **划水段要贴近水平**：α₀ 越小推力越高且不多耗电；峰值推力时刻的上下肢构型 γ_pk 只由 β₀ 决定。和我 04 号目标轨迹（z = −85 mm 的水平直线行程）一致。

### 可以直接拿来用的

- **F̄x / 4F̄SL 这个指标**，以后我做四腿直接用同一个口径，可以跟这篇同框比较。
- **无量纲化方式**：力 / ρU₀²W²、CT = 2F̄x,avg /(ρŪ²A)、功率系数 P̄avg。我现在一直用 mN 报结果，补一列 CT 才能跟别人比。
- **附录 A 那两张无关性验证图**的画法（三条曲线叠一张 F̄x(t) 图），直接照抄。
- **力矩口径**：Mx / My / Mz 绕同一原点在流固界面 (fluid-structure interface) 上积分；My,avg 恒为负。和我 V3trap 的 |M̄y| = 36.7 mN·m 是同一套说法。

### 它留下的空白，正好是我在做的

1. **它的腿在回程时面积一点没变小。** 我的第一套（120° 折扇 folding fan，收拢到 27% 面积）和第二套（刚性板绕桨杆**羽化 feathering** 90°，只剩 13%）消掉的就是这一项。我的 C6 系列已经量到：光是把收腿面积缩小，净推力从 49.3 涨到 56.7 mN（+15%），回程段相平均力从 −19.3 改善到 −5.9 mN。
2. **它的划水速度曲线 (velocity law) 是描视频得来的一条固定曲线**，DR 只是把它整体拉伸。我把速度律本身当设计变量（梯形 trapezoid vs 余弦 cosine），它测不到这一层。
3. **它没有可开合的状态**，所以没有"什么时候收、什么时候展"这个自由度。我扫出来的最优切换点 τ_c 在划水段的 82–86%。
4. **它不知道最优 DR 在哪。** 我这边有判据：最优占空比 (DUTY) 由回程与划水的有效阻力比 a_eff = (F_rec/F_pw)(v_p/v_r)² 决定，我的三种构型是 0.10 / 0.03 / 0.013。

### 对我的设计的具体启发

- **作动器量级。** 它用的是 **GXservo-X50（50 kg·cm）防水舵机 (waterproof servo)**，我选的 7465W 只有 5.8 kg·cm @ 8.4 V。但我的桨板面积只有它的三分之一（18.5 vs 55.8 cm²）、桨速慢 2–4 倍，估下来峰值力矩 0.4–0.6 kg·cm，余量很大。**提醒是反过来的**：桨板一旦放大到它那个尺度，力矩就从"随便什么舵机都行"变成真瓶颈。
- **D2w73 的判据要改。** 它的规律是推力涨则力矩涨、耗电涨。所以板加宽到 73 mm 这个算例，该看的是 F̄z/F̄x 和 |M̄y|，而不是净推力。
- **浮心 (center of buoyancy, CB) 要在重心 (center of gravity, CG) 之上**——它给的稳定性建议，M3 船体要照这个核一下。
- **一句可以直接引用的空白陈述：** *"the interaction between legged robots and fluid medium during the learning process remains unexplored"* ——正好当我 RL / 最优控制方向的动机。

## 关联知识

- **阻力型推进 (drag-based thrust) vs 升力型推进 (lift-based thrust)**：划水效率低，但陆上能走；身体波动 (body undulation) 和鳍摆 (fin flapping) 效率高，但上不了岸。这是所有腿式两栖机器人 (legged amphibious robot) 的根本折中。
- **浸没边界法 (immersed-boundary method, IBM)**：处理大位移运动边界的另一条路，和我用的 overset（重叠网格）并列。节点分成 fluid / solid / ghost / hybrid 四类。
- **三个可复用指标**：推力系数 CT、功率系数 P̄avg、腿间干涉比 F̄x / 4F̄SL。
- **三种推力模式的命名 (Trotting / Hindering / Separate Mode)**，比"两相/四相"更有物理含义，可以直接借用这套说法。

## 相关研究问题

- [[单腿最优划水轨迹如何定义]]
- [[回程阻力如何通过机构自由度消掉]]
- [[占空比 DUTY 的最优值由什么决定]]
- [[腿间干涉是增益还是损失]]

## 相关论文

- **Qu 2025**（Bioinsp. Biomim. 20:036012）：同样是四足划水，但是**实测**。趋势一致（划水段越短推力越大），但绝对值比这篇低 2–5 倍。两篇都发现"推力高的步态晃得更厉害"（Qu：四相比两相快 1.69× 但横摇 4.6×）。
- **Lin 2024**（arXiv 2409.14707）：腱耦合的折叠蹼 (tendon-coupled folding webbed feet)，把开合过渡时间缩短 45–67%，效率从 1.45% 提到 2.86%。它做的正是 Wang 缺的那个回程自由度。**Wang 给基线，Lin 给收益，我把两者放进同一套 CFD 里比。**

## 下一步行动

- 给我的结果表补一列推力系数 CT，才能跟这篇和 Qu 2025 同框比较
- 给 V3trap 补网格无关性 (mesh independency) 和时间步无关性两张图
- 把 V3 → V3trap 的 +32% 拆开：速度律、周期 T、占空比 DUTY 各占多少（别犯它在 DR 上犯的混淆）
- D2 跑完后，用"推力涨则力矩涨"的规律核对 D2w73
- 整机阶段直接用它的步态定义 (trotting / diagonal sequence / lateral sequence)，不重做步态扫描
- 核对 M3 船体浮心 (CB) 是否在重心 (CG) 之上

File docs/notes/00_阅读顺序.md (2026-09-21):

# BODY2 必读论文 —— 按你现在的进度排的阅读顺序

现状：V3 已由 CFD 选定（推力 49.3 mN、F̄_z/F̄_x 0.28），正在写报告，下一步是整机 4 相 vs 2 相、舵机能力核对、固件轨迹。
下面 14 篇按**什么时候读**排，每篇写清"翻到哪、看什么"。带 ⬇ 的可直接下载（跑 `下载_OA论文.sh` 或点 `论文索引.html`），带 🔒 的要走 TUM 图书馆（eaccess.ub.tum.de）。

---

## 第一梯队 —— 先读这三篇（各 30–40 分钟）

### 1. ⬇ Fish (1984) 《Mechanics, power output and efficiency of the swimming muskrat》
JEB 110: 183–201 · 文件 `01_Fish1984_muskrat.pdf`

**这是你仿生对象本身的定量测量。**别通读，直接翻这几页：
- **p. 190–191**：划频恒定 2.5 ± 0.06 Hz，靠加大摆幅提速；划水 0.18 s / 回收 0.22 s → **占空比 0.45**。和你的 V3 一模一样，是独立佐证，写进报告结论那一段。
- **p. 194**：回收相阻力只有划水相的 **33 %**；趾收拢 + 足旋后使迎流面积减少 **55.5 %**；回收耗功为划水的 20–39 %。
  → 对照你的扇：20.0 → 13.3 cm²，面积只减 33 %。**CLOSED_W 从 30 mm 往下调是有生物学依据的**，值得再跑一组 closed 算例。
- **p. 197–198**：最大机械效率 0.33。

### 2. ⬇ Wang 等 (2025)《A Computational Study on the Hydrodynamics of Bio-Inspired Quadrupedal Paddling》
Biomimetics 10(3): 148 · 文件 `02_Wang2025_quadruped_paddling_CFD.pdf`

**参数扫描和你几乎重合**（初始摆角 60/70/80° × 摆幅 20/30/40° × 划水相占比 50/33/25 % × 三种步态序列）。看这几点：
- 三种推力模式 Trotting / **Hindering** / Separate。Hindering = 前一条腿刚离开划水相的阻力抵消后一条腿的推力 —— **这正是你整机算例要判断的东西**，先看他们在什么相位差下出现。
- 对角/侧序列的水动力矩远大于小跑；推力上去，力矩和能耗同步上去。→ 你选 4 相还是 2 相时的直接依据。
- 方法：浸没边界法、**无自由面**。你的 overset + VOF **带自由面**正是差异点，方法章里点明。

### 3. 🔒 Qu 等 (2025)《Amphibious robotic dog: design, paddling gait planning, and experimental characterization》
Bioinspiration & Biomimetics 20(3): 036012 · DOI 10.1088/1748-3190/adcd1b

**平台最像、Frank Fish 共同作者、有真机实测。**看两件事：他们三种步态的划水相占比（**25 % / 33 % / 50 %**）与速度/稳定性的取舍；以及重心–浮心关系怎么设计来保证浮态稳定。这是你 V1/V2/V3 对比的直接对照组，也是速度指标的 benchmark（水中 0.16 m/s）。

---

## 第二梯队 —— 这周读（各 20–30 分钟）

### 4. ⬇ Lin, Guo, Badri-Spröwitz (2024)《Bird-inspired tendon coupling improves paddling efficiency by shortening phase transition times》
arXiv:2409.14707 · 文件 `04_Lin2024_tendon_coupling.pdf`

**和你的线驱动扇形脚蹼是同一个机构问题，而且指出了你还没试过的优化方向。**结论：效率提升不来自面积比，而来自把折叠↔展开的**过渡时间缩短 45–67 %**（全腱 2.86 % vs 无伸肌腱 1.45 % vs 被动桨 0.84 %；净推力 1.72 N vs 0.86 N）。
→ 对应你的 `FAN_CLOSE` 和那个 8 % T 的过渡：**不用改机构，只改线的预紧和松线相位就能试**。看他们的硬限位（joint limit）怎么做的。

### 5. ⬇ Csillag & Ribak (2025)《Underwater paddling kinematics ... surface swimming duck versus a diving duck》
JEB 228(9): jeb249274 · 文件 `05_Csillag2025_duck_paddling.pdf`

**支撑你报告里 F_z（垂向力）那一节。**水面型鸭子的蹼产生向上的力、与自身浮力对抗；潜水型低头约 16°、行程弧更小，把足力指向下方，作者证明后者才是水平游动的高效运动学。→ V3 把力矢量倾角从 20° 压到 8° 的生物学对照。
注意一个**矛盾**：两种鸭子的划水相都短于回收相，与你"短回收更好"相反。报告里明说（动物在省代谢能和控浮，机器人不需要）比回避好。

### 6. ⬇ Ribak & Gurka (2023)《The hydrodynamic performance of duck feet ... resembles oars rather than delta-wings》
Sci. Rep. 13: 16217 · 文件 `06_Ribak2023_duck_feet_oars.pdf`

**你准定常叶素模型最直接的合法性依据**：蹼足是阻力式的桨，不是三角翼，流场里没有前缘涡升力。看 C_D–攻角曲线（10° 时约 0.25 → 75° 以上约 1.5，法向力峰值在 55° 附近，30°–140° 之间力都稳）。结论对你有利：**攻角在很宽范围内力差不多，桨的俯仰精度要求不高**。

### 7. ⬇ Han 等 (2025)《Learn to Swim: Data-Driven LSTM Hydrodynamic Model for Quadruped Robot Gait Optimization》
ICRA 2025, arXiv:2505.03146 · 文件 `07_Han2025_learn_to_swim.pdf`

西湖大学，与你已有的 Cui 2026 同组。用约 300 万点实测力数据训 LSTM 代理模型 + NSGA-II 多目标步态优化，明确说经验/准定常公式低估非定常力。
→ **你的对照论证**：他们用 3 M 实测点换一个黑箱，你用 6 个 CFD 算例标定一个可解释模型、偏差 ±16 %。这段写进讨论很有力。

---

## 第三梯队 —— 写方法章时读

### 8. ⬇ Chen 等 (2022)《Dynamic modeling and experiment of hind leg swimming of beaver-like underwater robot》
Mechanical Sciences 13: 831 · 文件 `08_Chen2022_beaver_leg.pdf`
**你单腿"解析模型 + CFD + 实验"验证链条的现成模板**，全文免费，结构可直接对标。看他们怎么把叶素力耦合进 Newton–Euler。

### 9. ⬇ Hu 等 (2024)《Design and Reality-Based Modeling Optimization of a Flexible Passive Joint Paddle》
Biomimetics 9(1): 56 · 文件 `09_Hu2024_passive_joint_paddle.pdf`
**伪刚体模型 + 叶素理论 + 实验标定水动力系数**（力误差 0.51 %）—— 和你的做法同源，是"标定型准定常模型"的可引用先例。单舵机对称指令、不对称全来自铰链非线性，这个思路值得记住。

### 10. ⬇ ITTC 7.5-02-02-01 Resistance Test + 7.5-03-02-04 CFD Guidelines
文件 `10a_ITTC_resistance_test.pdf` / `10b_ITTC_CFD_guidelines.pdf`
**船体章的救命稻草。**7.5-02-02-01 明文写着规程**预设湍流激励**、修正就是为了避免层流 → "ITTC-57 摩擦线在 Re ≈ 3×10⁴ 不适用"不是你算错了。7.5-03-02-04 给网格、y⁺、自由面加密、计算域、时间离散阶数的可引用出处。

### 11. 🔒 Chen 等 (2019)《Application of an overset mesh based numerical wave tank...》Ocean Eng. 176: 97
+ ⬇ Windt 等 (2020) J. Ocean Eng. Mar. Energy 6(1): 55（文件 `11_Windt2020_overset_evaluation.pdf`）
**"为什么用 overset、为什么这么慢"的标准答案**：运动幅度大到一定程度 morphing 直接崩、overset 活下来，代价约 2× 运行时间。Chen 2019 里有**入水（water entry）**验证算例，是你桨穿越水线的最近参照。

---

## 第四梯队 —— 引言/背景

### 12. ⬇ Picardi 等 (2023)《Underwater legged robotics: review and perspectives》
Bioinsp. Biomim. 18 · 文件 `12_Picardi2023_underwater_legged_review.pdf`
引言里"为什么用腿划水而不是螺旋桨"的标准出处。

### 13. ⬇ Walker & Westneat (2000) + Fish (1996)
文件 `13_Walker2000_rowing_vs_flying.pdf`
划水（rowing）效率上限约 33 %，摆动翼（flapping）可超 80 %。**诚实交代你这一类推进方式的天花板**，然后说明增益只能从占空比、回收阻力、力方向对齐里挖 —— 正是你做的三件事。这段能让评审觉得你清楚自己在哪个框里。

### 14. 🔒 Kim & Gharib (2011)《Characteristics of vortex formation and thrust performance in drag-based paddling propulsion》
JEB 214(13): 2283
扇形（delta）桨的展向流远强于矩形桨 → 你 120° 扇形几何的正当性。另外：**柔性桨在快速加速段削平推力峰值但不损失总冲量** —— 如果 V3 的舵机峰值力矩 20 mN·m 成为瓶颈，这是一条"降峰不降冲量"的出路。

---

## 读完之后能回答的三个问题

1. **CLOSED_W 该不该往下调？**（Fish 1984 的 55.5 % vs 你的 33 %）
2. **过渡时间是不是比扇形展开角更值得优化？**（Lin 2024）
3. **整机该 4 相还是 2 相？**（Wang 2025 的 Hindering 模式 + 力矩代价）

---

*清单与 BibTeX 见上一级目录 `BODY2_相关文献清单.md` / `BODY2_refs.bib`（共 30 篇）。*

---

## 追加（2026-09-12）：脚蹼开合时机 / 结构无关的最优单腿行程

读 `03_最优行程理论与开合时机.md`（配 `fig_optimal_stroke_theory.png`、`fig_fold_timing_sweep.png`）。新增四篇：**Santos 等 2026**（arXiv 2602.20565，虾足机器人：面积峰值对准速度峰值、回收一开始就合）、**Kwak 等 2019**（Bioinspir. Biomim.，划水后加 relaxation phase）、**Niu 等 2026**（J. Bionic Eng. 23(2):750，四相时序的代理模型辨识）、**Richards 2011**（JEB 214:2381，桨面积要与执行器匹配）。BibTeX 已追加到 `BODY2_refs.bib`。

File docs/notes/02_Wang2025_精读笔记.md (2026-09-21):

# 精读笔记：Wang 等 (2025)《A Computational Study on the Hydrodynamics of Bio-Inspired Quadrupedal Paddling》

*Biomimetics* 10(3): 148 · [DOI 10.3390/biomimetics10030148](https://doi.org/10.3390/biomimetics10030148) · 开放获取
作者：Yihan Wang, Yumeng Cai, Bin Xie, Chi Zhu, Yunquan Li, Ye Chen（与 Qu 等 2025 的机器狗是同一批人，Yunquan Li 两篇都在）

配图：`fig_wang2025_compare.png`（数据录自论文 Table 2/3，生成脚本 `wang2025_compare.py`）

---

## 一分钟版

一篇纯 CFD 的参数扫描：一条四足划水机器狗模型，扫 **初始摆角 α₀ × 摆幅 β₀ × 划水相占比 DR × 三种步态序列**，共 27 个单腿算例 + 整机算例。三个结论对你有用：

1. **行程中心角越低，推力越大** —— α₀ 从 60° 升到 80°，单腿平均推力掉 43 %。你的 V3 把中心角从 106° 压到 95° 拿到更多推力，方向被独立验证了。
2. **压缩划水相 → 推力 ×2.4，但推力系数（≈ 效率）×0.55** —— 和你 V1 vs V2 的取舍（效率 2.84 vs 3.45 mN/mW）是同一件事。
3. **腿间干涉是正的**：整机推力always > 4 × 单腿推力，比值 1.02–1.87。**你用单腿 ×4 估整机是偏保守的**。但四相序列增益更大（1.17–1.71）的同时，三个轴的水动力矩都远大于两相小跑。

一个直接可用的推论（我从他们的机理 + 你的 DUTY 推的）：**V3 的 DUTY = 0.45 恰好适配两相步态**——两对腿错开 T/2，划水窗口 0.45 + 0.45 = 0.90，几乎不重叠、只留 2×0.05T 的空档；换成四相 T/4 偏移则相邻腿必然重叠 0.20T，正好落进他们说的 Hindering 模式。见图 D。

---

## 他们到底做了什么（第 2 节）

**几何**：上肢 10.6 cm、下肢 12.0 cm、肢宽 4.65 cm；前后腿间距 L = 32 cm、左右间距 D = 12.4 cm。比你的腿大 ~2.5 倍（你 50 mm 杆 + 42 mm 桨头 = 92 mm）。

**运动学**：⚠️ **没有解析式**。上肢角 α(t) 与下肢相对角 γ(t) 是从一段游泳狗的视频逐帧重建出来的曲线（Figure 1c），三个参数只是对这条曲线做平移/缩放/时间压缩：
- α₀ ∈ {60°, 70°, 80°}：整条曲线的偏置。Table 2 里峰值推力时刻的角度恒为 **α_pk = α₀ + 10°**。
- β₀ ∈ {20°, 30°, 40°}：角度范围的缩放。**γ_pk = 75° − β₀**。
- DR ∈ {50 %, 33 %, 25 %}：划水相占周期的比例。

⚠️ **论文里有一处自相矛盾**，引用时要小心：正文说"因为步进电机转速恒定、划水相时长固定，DR = 50/33/25 % 对应周期 T = 0.8/1.2/1.6 s"，但 Table 2 的 T 列明明是跟着 **β₀** 走的（β₀ = 20/30/40° → T = 0.8/1.2/1.6 s，与 DR 无关）。Table 2 的读法才自洽：同一 β₀ 下 DR 越小，桨尖均速 Ū 越大（β₀=20° 时 0.64 → 0.96 → 1.34 m/s），这只有在 **T 不变、划水相被压缩** 时才成立。所以**他们的"DR 降低"= 周期不变、划水划得更快**，不是狗式的"划水快 + 回收慢"。
→ 对你意味着：**他们的 DR 结论和你的 V1/V2 实验不是同一个变量**。你的 V1 vs V2 是划水速率相同、只改回收时长；他们是周期相同、只改划水速率。两者都指向"别把时间花在慢划水上"，但机理不同，报告里要分清。

**流动条件**：
- Re ≈ **3.0 × 10⁴**（按肢宽 W = 4.65 cm 与划水相桨尖均速 Ū = 0.64 m/s）。**你的桨头 Re ≈ 1.1 × 10⁴，同一量级** —— 这点很重要，说明他们的结论在你的雷诺数区间可以借用。
- ρ = 1 g/cm³，μ = 0.001 Pa·s；Re = O(10⁴) 所以**不加湍流模型**（和你单腿算例用 laminar 的理由一样，可以互相引用）。
- **机体固定（tethered，无位移）、刚性腿、无自由面**。计算域是 20L × 32D × 12L 的闭合长方体，六个外面都是零速度 + 零法向压力梯度 → 完全淹没、没有空气–水界面。
- 网格 290 × 160 × 160 非均匀笛卡尔，桨周围 Δx = Δy = Δz = 0.25 cm；Δt = 2×10⁻⁴ s。无关性验证扫了 0.30/0.25/0.20 cm 与 3/2/1×10⁻⁴ s（附录 A）。求解器是自研的 **sharp-interface 浸没边界法**。

**力的定义**：
- 推力无量纲化用 **ρ_f U₀² W²**，其中 U₀ = 0.42 m/s（β₀=40°、DR=50 % 的桨尖速度）对所有算例统一使用，所以不同算例的 F̄x 曲线可以直接叠着看。
- 推力系数 **C_T = 2 F_x,avg / (ρ_f Ū² L² W)**，这里的 Ū 是**各算例自己的**桨尖均速 —— 所以 C_T 才是效率类的量（除掉了速度）。
- 力矩 M_x/M_y/M_z（横摇/纵摇/首摇）对流固界面积分，原点取四条腿上肢铰链的中点。**论文没给力矩的无量纲化因子，也没有力矩数值表，只有图 9/10 的曲线**。
- 功率 P(t) = −∫ F·u dΓ；平均功率系数用 ρ_f Ū³ L² W / 2 归一。

---

## 结果（第 3 节）——哪几段该细看

### ① Table 2（单腿，27 行）：三个参数的趋势
**这是全文最该抄进你报告的一张表。**

- **α₀ ↑ → 推力 ↓，单调。** β₀=20°、DR=50 % 时：F̄x,avg = 0.75 → 0.59 → 0.43（α₀ = 60/70/80°），**降 43 %**；峰值推力 F̄x,pk = 10.53 → 9.90 → 8.79。机理他们说得很清楚：**"前倾、上下肢更展平的位姿在峰值推力时刻始终产生更低的推力"**。
  → 这正是你 V3 的机理（把行程中心压低，出力最大那段桨更接近竖直）。但**注意角度定义**：他们的 α 是上肢相对机体的位置角，你的 ψ 是摇臂相对 +x 的方向角，两者基准不同。引用时别直接对数字，只对**方向**：低中心角 = 更多推力。用之前先看 Figure 1b 确认他们的角度零点。
- **β₀ ↑ → F̄x,avg ↓，但 C_T ↑。** 因为 T ∝ β₀（0.04 s/度），摆幅加大的同时周期也加长、桨尖变慢。所以"大摆幅推力小"在他们这里是**周期变长的副作用**，不是摆幅本身不好 —— 这点论文没有拆开，是个可以批评的地方，你在报告里可以指出（你自己的 V3 把 SWEEP 从 60° 降到 50° 同时缩短周期，是把两者解耦了）。
- **DR ↓ → 推力大涨。** F̄x,avg 0.75 → 1.27 → 2.35（β₀=20°, α₀=60°）。但 C_T 同时 0.24 → 0.19 → 0.18。**推力 ×2.4、效率 ×0.55**（9 组均值，见图 B）。
- **峰值时刻随 DR 后移**：t_pk ≈ 0.58–0.63 T（DR=50 %）→ 0.71–0.74 T（33 %）→ 0.80–0.81 T（25 %）。

### ② 三种推力模式（Figure 7–8）——**你整机步态决策的核心**
- **Trotting Mode**（两相小跑，DR = 50 %）："每一对对角腿在周期内交替、等量地贡献推力，而它的贡献被另一对对角腿削弱。" 一个周期两个推力峰，间隔 T/2。
- **Hindering Mode**（四相序列，DR = 33 %）："单条腿的推力被前一条腿离开划水相、进入回收相时产生的阻力显著削弱。"
- **Separate Mode**（四相序列，DR = 25 %）："四条腿各自独立贡献推力，形成周期内均匀分布的紧凑四峰波形。"

**关键的数量关系**（论文没明说，我替你算了）：四条腿按 T/4 错开时，只有 **DUTY ≤ 0.25** 才进得了 Separate 模式；DUTY 越超过 0.25，相邻腿重叠越多、Hindering 越重。
→ 你的 V3 是 **DUTY = 0.45**，四相时相邻腿重叠 0.20 T，**必然是 Hindering**。而两相（对角对错开 T/2）时 0.45 + 0.45 = 0.90，**几乎不重叠**，只在 τ ∈ [0.45,0.5) 和 [0.95,1) 各有 0.05 T 的空档。图 D 画的就是这个。
→ **推论：V3 该配两相步态。** 若想用四相吃到更大的干涉增益，就得把 DUTY 降到 0.25 附近 —— 但那是另一个步态，要重跑 CFD。

### ③ Table 3（整机 ÷ 4×单腿）：干涉增益
| (α₀, β₀) | 两相小跑 | 四相 DR 33 % | 四相 DR 25 % |
|---|---|---|---|
| (60,20) | 1.12 | 1.20 | 1.00 |
| (70,20) | 1.18 | 1.42 | 1.16 |
| (80,20) | 1.09 | 1.52 | **1.87** |
| (60,30) | 1.13 | 1.33 | 1.26 |
| (70,30) | 1.06 | 1.37 | 1.34 |
| (80,30) | **1.02** | 1.50 | 1.56 |
| (60,40) | 1.20 | 1.17 | 1.04 |
| (70,40) | 1.26 | 1.44 | 1.20 |
| (80,40) | 1.19 | 1.71 | 1.47 |

**全部 > 1**：作者结论是"腿间相互作用对推力生成有正面影响，总推力超过单腿推力的四倍"。
→ **你的整机估算（单腿 23.5 mN × 4）是下限**，实际可能高 5–70 %。这句话值得写进你的报告。
→ 两相增益 1.02–1.26（窄），四相 1.17–1.71（宽且更大）。

### ④ 力矩与能耗（Figure 9–10 + 第 4 节）
- **只有定性结论，没有数值表**："对角与侧序列步态的 M_x、M_y、M_z 彼此非常接近……相比之下小跑步态的三个力矩都小得多，尤其是 M_x（横摇）和 M_z（首摇）。" DR 越小力矩越大（Separate 模式最大）。
- **能耗**：α₀=80°、β₀=40° 固定，DR 从 50 % → 33 % → 25 %，单周期做功 **1.37 J → 2.40 J → 4.37 J**（涨 3.2 倍）。注意 Table 4 里归一化的功率系数反而是降的（3.50 → 2.41 → 1.62），因为归一化因子含 Ū³。**引用时务必用有量纲的 1.37/2.40/4.37 J，别用归一化值，否则会得出相反的结论。**
- 作者提醒：用低 DR 的四相序列时，**必须配基于实时振动信号的反馈控制**，否则机体姿态会抖。

### ⑤ 步态定义（Figure 1d）
- 两相小跑：对角对（LF+RH / RF+LH）同相，两对错开 **T/2**。
- 四相对角序列：**LF → LH → RF → RH**，依次错开 **T/4**。
- 四相侧序列：**LF → RH → RF → LH**，同样 T/4。**推力几乎与对角序列相同**（所以四相选哪种只看力矩和控制方便）。
- 附带一个细节：垂向力比推力**超前约 6.25 % 周期**（T/16）。你做垂向力分析时可以对照。

---

## 和你的工作怎么接

| 论文 | BODY2 | 关系 |
|---|---|---|
| α₀ 60/70/80° | PSI_START / 中心角 106° → 95° | **方向一致**：低中心角 = 高推力。但角度定义不同，只引用方向 |
| β₀ 20/30/40° | SWEEP 60° → 50° | 不可直接比：他们的 T 随 β₀ 变，混淆了两个变量 |
| DR 50/33/25 % | DUTY 0.50/0.45/0.35 | **不是同一个实验**：他们 T 不变压缩划水（= 提速），你 V1/V2 是速率不变改回收 |
| C_T 随 DR 降 | F̄x/P̄ 2.84（V1）vs 3.45（V2） | **同一个取舍**，可互相印证 |
| 整机/4×单腿 = 1.02–1.87 | 你按 4 × 23.5 mN 估整机 | **你的估计偏保守**，可以引用这条 |
| 浸没边界、无自由面、机体固定 | overset + VOF、**有自由面** | **你的差异化卖点**，方法章里点明 |
| Re ≈ 3×10⁴ | 桨头 Re ≈ 1.1×10⁴ | 同量级，结论可借用；两边都不加湍流模型 |

**能直接写进你报告的三句话**：
1. "腿间干涉为正（Wang 等 2025，整机推力为 4 × 单腿的 1.02–1.87 倍），因此本文按单腿 × 4 给出的整机推力估计是保守下限。"
2. "低行程中心角带来更高推力的趋势与 Wang 等 (2025) 的 α₀ 扫描一致（α₀ +20° → 推力 −43 %）。"
3. "在 DUTY = 0.45 下，四相 T/4 序列会使相邻腿的划水相重叠 0.20 T，落入 Wang 等 (2025) 所述的 Hindering 模式；两相对角步态则几乎无重叠，因此本文的整机算例采用两相步态。"

**这篇论文没做、你能补的**：
- 有自由面的整机算例（他们完全淹没，闭合盒子）。
- 自由漂浮（他们机体固定，所以升沉/纵摇的实际后果没算）。
- 力矩的**定量**对比（他们只有曲线）。
- 变面积桨（他们是刚性等宽肢，没有脚蹼开合）。
- 把 β₀ 和 T 解耦（他们混在一起了）。

**引用前要核实的两点**：① 他们 α 的角度零点（看 Figure 1b），确认"低 α₀ = 桨更竖直"；② T 到底跟 DR 还是跟 β₀ 走（正文与 Table 2 打架，我倾向 Table 2）。

---

*笔记基于 MDPI 开放获取全文（Table 2/3 数值逐行核对过，与正文引用的整机推力互相验算一致：4 × 1.80 × 1.16 = 8.35 ✓）。*

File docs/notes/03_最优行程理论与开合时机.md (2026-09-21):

# 03 · 脚蹼开合时机（fold timing）与结构无关的最优单腿行程

配图：`fig_optimal_stroke_theory.png`（准定常理论四图）、`fig_fold_timing_sweep.png`（用现有 CFD 算例扫开合时刻）
脚本：`optimal_stroke_theory.py`、`fold_timing_sweep.py`（后者只用 `results_leg/`、`results_verify/V1–V3` 已有的 open/closed 数据，不需要新算例）

## 0 一句话

文献里没有"折叠桨最优开合时刻"的闭式解，但生物、机器人和 CFD 三方面给出的定性结论完全一致：**划水一开始就尽快全开、整个划水相保持全开、在减速段（而不是划水结束）就收拢、回收相尽快返回、过渡越短越好**。定量的部分（占空比 DUTY*、速度律、开合相位）可以先用准定常（quasi-steady）模型算出闭式解，再用 CFD 校正非定常效应——用你现有的 open/closed 算例已经能做第一步：V3 把收扇提前到 τ ≈ 0.36（划水相 80 % 处）推力 +5 %，开扇提前到回收末段 τ ≈ −0.05 再 +4 %。

## 1 有没有人研究过"什么时候开、什么时候合"

| 来源 | 系统 | 关于开合时机的结论 | 对 BODY2 的含义 |
|---|---|---|---|
| Fish 1984, J. Exp. Biol.（麝鼠） | 生物 | 划水相 0.18 s / 回收相 0.22 s（DUTY 0.45）；回收相把脚掌合拢、趾并拢，迎流面积 −55.5 %；回收阻力仍占推力的 33 % | 生物的 DUTY 与折叠比对应（见 §2 理论：a = 0.445 → DUTY* = 0.445） |
| Santos, Brown, Kim, Tack, Wilhelmus 2026, arXiv 2602.20565（虾游泳足机器人，cupping） | 机器人 + PIV | 外肢 "abducts rapidly during the power stroke, maximizing projected area at peak flow velocity, and adducts early during the return stroke"；杯状角 20–40° 最好 | **面积峰值要对准速度峰值；回收一开始就合上** |
| Kwak, Lee, Bae 2019, Bioinspir. Biomim.（水甲虫式铰接腿 + 柔性附肢） | 机器人 | 在划水相与回收相之间加一段 relaxation phase（停顿）可增加每冲程行进距离 | 划水结束后**停一下再回收**（让停止涡脱开、身体滑行） |
| Lin et al. 2024（腱耦合自折叠蹼足） | 机器人实验 | 折叠/展开过渡时间 TP1 −67 %、TP2 −45 % 时，效率 0.84 % → 1.45 % → 2.86 %，输入功不变 | **损失在过渡本身**：开合要快、要准 |
| Niu, Lin, Guo et al. 2026, J. Bionic Eng. 23(2):750–770（水禽式蹼足，滑块–四杆折叠+回缩） | 机器人 + 代理模型 | 把周期分为 extension / power stroke / flexion / retraction 四相并做 surrogate-assisted 参数辨识：影响排序 划水角 > 周期基准时间 > 各相时间缩放系数；"flow attachment" 是推进效率的主导因素 | 相位时长是二阶量，幅值与周期是一阶量；蹼面要保持贴流（不失速、不早分离） |
| Kim & Gharib 2011, J. Exp. Biol. 214:2283（单块平板划水，Re ≈ 2×10⁴，行程 106°，梯形 vs 正弦角速度） | 实验 PIV | 推力时间历程跟随涡强的时间变化，而不是准定常 v²；柔性板削平力峰但总冲量不变 | **起动附加质量 / 停止涡不可忽略** → 准定常只能给出趋势，量要靠 CFD |
| Walker & Westneat 2000, Proc. R. Soc. B（rowing vs flapping 叶素模型） | 理论 | 划桨（drag-based rowing）在低速、加速、机动时更有效，巡航高速时拍翼更省；划桨的效率取决于回收相能否把面积"羽化"到最小 | 我们的准定常模型就是这一类（blade-element） |
| Richards 2011, J. Exp. Biol.（真肌肉驱动的机器蛙脚） | 机器人 | 脚面积翻倍，肌肉在水中的输出功率反而从 41.6 降到 25.1 W/kg | **面积要与执行器匹配**：舵机力矩/速率有限时，桨不是越大越好 |
| Herrera-Amaya & Byron 2021, Integr. Comp. Biol.（往复划桨的时空不对称） | 理论/实验 | 往复划桨的净推力只来自两种不对称：spatial asymmetry（开合改变面积）与 temporal asymmetry（划水快、回收慢或反之） | 开合时机 = 空间不对称；DUTY = 时间不对称；两者要一起优化 |
| Wang 2025 / Qu 2025（狗腿式机器人） | CFD / 实验 | 刚性腿，没有开合；给出 DUTY（DR）与推力/效率的权衡：DR↓ 推力 ×2.4、C_T ×0.55 | 见 `02_Wang2025_精读笔记.md` |

结论：所有来源都指向同一套"开合时序"，但没有人给出**最优相位的数值**（例如"收扇应在划水相的百分之几"）——因为它取决于折叠比、速度律和非定常效应，只能针对具体桨算。下面把能闭式求解的部分先算出来。

## 2 准定常理论（能闭式回答的部分，图 `fig_optimal_stroke_theory.png`）

模型：阻力式推进（drag-based propulsion）F = ½ρC_d A (v − U)²，划水相 A = A_max、回收相 A = A_min，两相扫过同一弧长 L，机体速度 U。

**(A) 最优占空比只由折叠比决定。** 令 a = A_min / A_max、x = v_r / v_p（回收速度 / 划水速度）。U = 0（系泊）时周期平均推力
T̄ ∝ (1 − a·x)·x / (1 + x)，
对 x 求极值得 **x\* = √(1 + 1/a) − 1，DUTY\* = x\*/(1 + x\*)**。
- a = 0.445（麝鼠，面积 −55.5 %）→ DUTY\* = 0.445，麝鼠实测 0.45。理论与生物一致。
- a = 0.67（BODY2 几何比，CFD 里收拢宽 30 mm）→ DUTY\* = 0.37。
- a_eff ≈ 0.22（BODY2 CFD 有效比：由 V3 的 F_rec/F_pw = 19.4/133.3 = 0.146 = a·x²，x = 0.45/0.55 反推；含蜷缩抬起的效果）→ DUTY\* = 0.58，但回收速率不能超过划水速率（舵机速率上限）时取 **min(DUTY\*, 0.5) = 0.50**。
- 物理含义：折叠越好（a 小），回收越该快（DUTY 越大）；折叠差（a > 0.5），回收就该慢下来省阻力。V3 的 0.45 已经在最优区，V2 的 0.35 偏低是因为它牺牲了划水时间。

**(B) 速度律：匀速划水（constant slip velocity）在两种意义下都最优。** 同一舵机峰值速率、同一划水时长下，梯形律（12 % 加减速 + 匀速）比余弦律的冲量 ∫v²dt 高 1.68 倍、能量 ∫v³dt 高 1.93 倍（图 C）；反过来固定冲量时，Hölder 不等式给出 ∫v³ ≥ I^{3/2}/τ^{1/2}，等号当且仅当 v 恒定——即**匀速划水在给定推力下耗能最少**。现有全部算例都是余弦律，把速率预算浪费在起止段。

**(C) 开合窗口：只在 v > U 时张开。** 桨速低于机体速度时张开的桨只产生阻力（图 C 红区）。U/v_max = 0.3 时余弦律只有 81 % 的划水相真正推进，梯形律 93 %。所以准定常给出的规则是：**开扇 = v 刚超过 U 的瞬间，收扇 = v 回落到 U 的瞬间**；U = 0 时准定常说"划水结束才收"，但 §3 的 CFD 说要更早。

**(D) 效率与推力的最优不同。** 阻力式推进的 Froude 型效率 η = U/v_p（Alexander / Fish）：给定推力时，**面积越大、划得越慢越省**；给定舵机速率/力矩时，**匀速、全开、尽量快**推力最大。所以"最优"要先定目标：巡航效率 → 大桨慢划；最大速度/加速 → 图 D 的时间线。Richards 2011 提醒面积要与执行器匹配。

## 3 用现有 CFD 算例扫开合时刻（图 `fig_fold_timing_sweep.png`，第 3 周期）

两态合成规则与 `analyze_verify.py` 相同，只是切换时刻可变：τ ∈ [τ_o, τ_c) 用 open 算例的力，其余用 closed。没有模拟折扇过渡本身，两条时间历程的尾流也各自独立，所以是一阶灵敏度。

| 步态 | DUTY | 现用 F̄x [mN] | 收扇最优 τ_c → F̄x | 提前 0.1 T | 推迟 0.1 T | 推迟 0.2 T | open−closed 推力差过零 τ | 开扇最优 τ_o → F̄x | 晚开 0.05 / 0.15 T |
|---|---|---|---|---|---|---|---|---|---|
| 现步态 | 0.50 | 23.5 | 0.42 → 24.1 | 24.0 | 15.8 | 18.0 | 0.42 | −0.15 → 26.5 | 22.1 / 19.3 |
| V1 | 0.49 | 51.2 | 0.40 → 52.9 | 52.9 | 45.2 | 36.8 | 0.40 | −0.05 → 53.0 | 48.1 / 40.6 |
| V2 | 0.35 | 34.2 | 0.28 → 35.6 | 35.2 | 32.2 | 28.9 | 0.28 | −0.07 → 34.9 | 31.8 / 23.3 |
| V3 | 0.45 | 49.3 | **0.36 → 51.7** | 51.6 | 44.0 | 34.3 | 0.36 | **−0.05 → 51.4** | 45.4 / 36.1 |

读法：
- **收扇要在减速段中间，不是划水结束。** V3 在 τ ≈ 0.36（划水相 80 % 处，桨速已降到峰值的 59 %）open 的推力就低于 closed——减速时张开的扇附加质量（added mass）反过来拖后腿。提前收 0.1 T 赚 2–5 %，推迟 0.1 T 亏 10 %，推迟 0.2 T 亏 25–30 %：**宁早勿晚**。单位功率推力 F̄x/P̄ 的峰值也在提前一侧（V3 3.05 → 3.16 N/W）。
- **开扇在回收末段速度过零前 ≈ 0.05 T 最好**（V3 +4 %）：过零前桨在减速，附加质量给的是正推力，而此时前向速度已很小、阻力代价低。晚开 0.05 T 亏 3–4 %，晚 0.15 T 亏 20 %。
- 这与 Santos 2026（面积峰值对准速度峰值、回收一开始就合）和 Lin 2024（过渡要短）一致，且给出了 BODY2 自己的数字。

## 4 结构无关的"理论最优单腿行程"（图 D 时间线）

先不管连杆，只问一块可开合的桨在水里应该怎么动：

1. **划水相（power stroke）**：桨面垂直于运动方向，尽量平动（arm 上的桨则把行程居中在竖直位置，±25–30°，V3 的 120→70° 就是这个思路）；速度律取梯形（舵机允许的最短加减速 + 匀速在速率/力矩上限）；全开；入水最深（离自由面 ≥ 1 个桨弦长，离船体远）。占周期 DUTY ≈ 0.50（速率受限）或按 a 用 §2 公式。
2. **过渡 1（收扇 + 停顿）**：在减速段、桨速降到 ≈ 0.6 v_max 或 ≈ U 时收扇（V3 对应 τ ≈ 0.36–0.40）；随后停 0.03–0.05 T 让停止涡脱开（Kwak 的 relaxation phase）。
3. **回收相（recovery）**：已收拢到 A_min，抬高/蜷缩，走与划水不同的路径（不穿自己的尾流），以舵机允许的最高速率返回（a_eff < 0.5 → x\* > 1）。
4. **过渡 2（开扇）**：回收末段速度过零前 ≈ 0.05 T 开始张开，必须在划水相 v 超过 U 前全开。

写成 BODY2 的参数就是：`T` 尽量短（受舵机速率）、`DUTY` 0.45–0.50、`PSI_START` 使行程居中 90°、`SWEEP` 50–60°、速度律 trapezoid（ramp 10–15 %）、`FAN_CLOSE` ≈ 0.8·DUTY、开扇提前 0.05 T、回收 `PHI_RET` 尽量小、`SWITCH_FRAC` 尽量小（快收快放）。

## 5 为什么还要 CFD（准定常漏掉的四件事）

- **起动附加质量**：梯形律的急加速产生力峰（Kim & Gharib），舵机力矩可能跟不上 → 加减速比例要用 CFD + 舵机力矩曲线一起定。
- **停止涡 / 减速段**：§3 已经看到减速段张开的桨是负贡献，收扇相位要按桨型单独算。
- **尾流再捕获（wake capture）与腿间干涉**：回收路径穿不穿尾流、四腿相位（Wang/Qu：整机 > 4×单腿）只能三维 CFD。
- **自由面**：桨离水面 < 1 弦长时兴波/通气，需要 interFoam；桨深则可继续用单相。

## 6 下一步（最省算力的顺序）

1. **零成本**：用 `fold_timing_sweep.py` 的结果，把 V3 的 `FAN_CLOSE` 设为 0.36–0.40，开扇提前 0.05 T（固件里就是 open 指令提前 40 ms）。
2. **2 个算例**：V3 + 梯形速度律（`leg_dynamics.py` 加 `VEL_LAW=trap RAMP=0.12`，`make_leg_cfd` 只建桨，任何轨迹都能给定）——验证图 C 的 1.7×；V3 + 划水后停顿 0.04 T（回收相压缩）——验证 Kwak。
3. **1 个算例**：closed 用真实折扇收拢宽（量一下，估 8–12 mm）——a 从 0.67 → ≈ 0.3，直接决定 DUTY\* 落在哪。
4. 之后再谈四腿相位与整机。

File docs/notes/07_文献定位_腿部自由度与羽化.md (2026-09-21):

# 07 · 文献定位：腿部自由度、羽化、升力型 —— 有没有人做过（2026-09-17）

查两个问题：(A) 有没有人论证过"划水腿需要几个自由度才能独立控制桨板姿态"；(B) 有没有人在**同一条肢体**上对比过阻力型和升力型。

结论：**(A) 是空白，(B) 已经有人做了。**

## A. 腿部自由度 —— 空白

没有任何一篇可验证的论文写过"平面 2 自由度腿在位置确定后姿态就被锁死，所以需要第 3 个自由度"。也没有人做过划水腿的 2-vs-3 DOF 权衡研究。

水下腿式机器人的主流是 **3 DOF/腿**，但**三个都是位置自由度**（两个矢状面 + 一个髋部横滚），没有一个是姿态自由度。桨板姿态被三种方式绕开：

| 绕法 | 代表 | 细节 |
|---|---|---|
| 末端做成对姿态不敏感的形状 | Molinaroli et al. 2026, arXiv:2609.09217 | 3 DOF/腿（五杆并联 + 髋滚），末端是**多孔空心球**，理由是 "increase drag without introducing asymmetric force patterns" |
| 姿态靠被动铰 / 腱耦合自然发生 | Lin 2024 (arXiv 2409.14707)；Bazaz Behbahani & Tan 2016；Hu 2024 | 5 关节只驱动 2 个，蹼靠腱开合，"without actuators" |
| 只做离散模式切换 | Kashem et al. 2019, Robotics 8(3):77 | 2 DOF/腿：Klann 连杆走行程 + 一个舵机把脚在 0°（陆）/80°（水）之间切换，不随相位调制 |

**最锋利的引用钩子**：2026 年那篇水下四足机器人有 3 个自由度，却**特意**把末端做成多孔球以回避姿态不对称——这等于默认它的三个位置自由度管不住姿态。可以直接用来点明这个缺口。

一个反向的声音：Lin 2024 论证的是**不需要**加第三个舵机，用腱耦合的被动姿态就够，并给出了效率增益。这是我的论点最强的对手，引言里必须正面处理。

**唯一可能已有 DOF 表的地方没打开**：Picardi & Calisti, "Underwater legged robotics: review and perspectives", Bioinspir. Biomim. 18 (2023), DOI 10.1088/1748-3190/acc0bb —— IOP 的 robots.txt 挡住了。**下结论前必须用 TUM 的访问权限把这篇拉下来核一遍。**

## B. 同一肢体的阻力型 vs 升力型 —— 已经做过，不是空白

**Baines et al. 2022, Nature 610:283–289**（ART 变形海龟，DOI 10.1038/s41586-022-05188-w）是决定性的一篇。每条肢体 **3 DOF，全在肩部**：前后摆 θ、上下摆 φ、**攻角 α**——这是我验证到的唯一一台有专门姿态自由度的机器人。同一个变形鳍跑两种步态：

- 划水（阻力型）：只有 **27%** 的行程产生推力，**COT ≈ 5**
- 拍动（升力型）：**95%** 的行程产生推力，**COT 最低 3**（40° 攻角偏置）
- 划水的加速度更高，拍动的持续效率更好

**Drago et al. 2025, Biomimetics 10(12):831**（海狮前鳍，Fish 是共同作者）粒度更细，3 DOF：拍动 θ_f、扫掠 θ_s、**扭转 θ_t（= 羽化）**。关键结果：

- power phase 推力峰值 **2.6 N**，最优扭转 **45°**
- paddle phase 推力峰值 **1.85 N**，最优扭转 **0°**（垂直）
- 合成行程 **3.8 N**

**两个相位的最优姿态完全相反**——这是"必须有一个随相位变化的姿态自由度"最强的定量证据，直接支持三连杆。

该文还有一条对我不利但必须承认的观察：即使有 3 个串联自由度，由于"dynamic kinematic coupling"，上游关节会重定向下游轴，世界坐标系里的鳍俯仰**并不是干净解耦的**。我图里"姿态与位置解耦"的说法要收一收。

**Fish 1996, Amer. Zool. 36(6):628–641**：阻力型推进效率 **≤ 33%**，升力型 **> 80%**。这是所有人引的生物学基线。

## C. 被动铰路线的先例

- **Bazaz Behbahani & Tan 2016, Bioinspir. Biomim. 11(3):036009** —— 最接近我的"折中方案"：一个舵机 + 柔性条构成**被动羽化关节** + **机械限位**，划水时限位顶住、回程时自由羽化。频率 ≥ 1.3 Hz 时胜过刚性关节；2 Hz 时 16 cm/s；机械效率 **11–64%**（随关节刚度和频率）。
- **Hu et al. 2024, Biomimetics 9(1):56** —— 柔性被动关节桨（FPJP），串联 N 个被动关节 + 1 个主动杆，**两侧凸起限位**在划水时锁平，回程时被水动力压垮。方法是伪刚体模型 + 叶素理论 + 数据驱动修正，无 CFD。
- **Santos et al. 2023, Sci. Rep. 13:9574**（Pleobot，磷虾游泳足）—— 2 个主动关节 + 1 个**被动**展开关节，回程时外肢与内肢重叠以减小轮廓面积。

## D. 两个真正的空白（对我的算例表直接有用）

1. **没有任何一篇报告划水/回程的迎流面积比或阻力比。** 全是定性描述（"profile area is reduced"）。我的 27% / 13% 是可以直接填进去的量。
2. **没有任何一篇做过同一平面形状下"刚性桨 vs 羽化桨"的对照实验或对照算例。** —— 这说明 **D2nof 这个算例的价值比原先设想的高得多**，它不是凑数的对照，而是文献里没有的那个数。

## E. 待核实 / 数字冲突

- **Lin 2024 的效率数字对不上**：我之前的笔记记的是 1.45% → 2.86%，这次查到的是"2.86 ± 0.12% vs 被动桨 0.84 ± 0.09%（2.39×）"。2.86/0.84 = 3.4，和 2.39× 也不自洽，可能存在多个对照组。**引用前必须翻原文确认。**
- 三篇没打开：Picardi & Calisti 综述（IOP）、"Optimal design and implementation of an amphibious bionic legged robot"（Ocean Engineering，Elsevier 付费墙）、Long et al. 2006 Madeleine（"Four flippers or two?"）。前两篇用学校 VPN 应该能拿到。

## F. 对引言的定位建议

可以这样站位：升力型比阻力型高效是 30 年前就有的结论（Fish 1996），同一肢体上的验证也已经做过（Baines 2022、Drago 2025）；被动羽化是成熟路线（Bazaz Behbahani & Tan 2016 起）。**尚未有人回答的是：在腿式划水这个具体形态下，把桨板姿态变成一个独立可控量，究竟值多少推力和效率，以及它要求腿有几个自由度。**前半句用 CFD 量化（D2 系列），后半句用运动学论证（双连杆 vs 三连杆图）。

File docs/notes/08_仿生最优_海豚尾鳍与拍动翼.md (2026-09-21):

---
type: note
title: 仿生最优解：海豚尾鳍与拍动翼的原理与设计参数
Annotator: Lu (Xiaotian Lu)
date_created: 2026-09-18
---

# 08 · 仿生最优解：从原理到 CFD 参数

目的：**在算之前**，把拍动翼推进的最优运动学参数从文献里定下来，而不是靠准定常模型猜。分两块——工程上的拍动翼正典（heave + pitch foil），和生物上的海豚尾鳍实测。

## 一、原理：推力从哪来

拍动翼的推力机制在 Triantafyllou 1991（Phys. Fluids A 3:2835）里讲得最清楚：翼在每个半周期的交替侧形成一个**中等强度的前缘涡 (LEV)**，它向下游对流并与后缘涡相互作用，最终形成**反卡门涡街**——即一股向后的射流，反作用即推力。

关键在于**尾流不稳定性的频率匹配**：尾流大尺度结构由平均射流剖面的拐点决定，当拍动频率与尾流空间放大率最大的频率重合时效率最高。该理论预言最优 Strouhal 数 **0.25–0.35**，并预言鱼类和鲸豚的尾鳍应当工作在这个区间——后来被生物实测证实。

Anderson 1998 的原话：控制 LEV 与后缘涡相互作用的**关键参数是俯仰与沉浮之间的相位角**。

## 二、工程正典：拍动翼的最优参数

**定义先统一（最容易出错的地方）：St = f·A/U，其中 A 是后缘（或沉浮）的峰峰行程 = 2h₀。** 很多文献的 2 倍差异都出在这里。

| 来源 | 方法 / Re | 最优点 |
|---|---|---|
| Anderson et al. 1998, JFM 360:41 | 实验 Re = 4×10⁴，NACA 0012，AR 6，俯仰轴 1/3 弦 | **η = 87%**：h₀/c = 0.75、**α_max = 20.2°**、**ψ = 75°**、**St = 0.30**，C_T ≈ 0.67 |
| Read, Hover & Triantafyllou 2003, JFS 17:163 | 实验 Re = 4×10⁴，同装置 | 效率峰 η = 71.5%（St 0.16，推力极小）；**实用平台 η = 50–60%，α_max 15–25°**；代表点 η 55.6%、C_T 0.79（α 20°、St 0.40）。**最大推力 C_T = 2.41**：α_max 30–35°、ψ = 100°、**St = 0.60**、h₀/c = 1.0，η 降到 43–49% |
| Triantafyllou et al. 1991 | 尾流稳定性理论 | 最优 **St = 0.25–0.35**，效率峰在 0.25 附近 |
| Taylor, Nudds & Thomas 2003, Nature 425:707 | 42 个物种比较 | **0.2 < St < 0.4**，飞行与游泳动物巡航时收敛到同一区间 |
| Floryan et al. 2017, JFM 822:386 | 实验 Re = 4780，标度律 | C_T ~ St²；**η ∝ 1/f\***，即**大幅度 + 低频率更高效**，直到黏性阻力占优 |

### 结论（工程侧）

- **St**：效率取 **0.25–0.35**；纯推力取 **0.6**（效率掉到 0.43–0.49）。两者相差一倍多，必须先决定优化目标。
- **α_max**：**15–25°，中心 20°**。低于 10° 推力太小，高于 35° 前缘涡分离、效率崩。
- **相位 ψ**：**75–90°，俯仰领先沉浮**。Anderson 最优 75°，Read 效率最优 90°、推力最优 100°。
- **俯仰轴**：Anderson 与 Read 全套数据都锚在 **1/3 弦**。但**没有任何一篇做过系统的枢轴位置扫描**——1/3 弦是被验证的惯例，不是被证明的最优。Lighthill 的月牙尾理论反而给出"俯仰轴在后缘"，Princeton 组用前缘。**分歧很大，应当作扫描变量。**
- **沉浮幅值**：**h₀/c = 0.75–1.0**。0.25 明显太小。

## 三、生物实测：海豚尾鳍

| 参数 | 数值 | 来源 |
|---|---|---|
| Strouhal 数 | **0.26 ± 0.05**（delphinids, n = 248）；74% 落在 0.2–0.3 | Rohr & Fish 2004, JEB 207:1633 |
| 效率峰所在 St | **0.225 < St < 0.275** | 同上 |
| 峰峰沉浮幅值 | **0.20 ± 0.03 体长**（四个物种 0.18–0.21 L） | Fish 1993, JEB 185:179；Fish 1998 |
| 最大攻角 | **α_max = 23.17 − 1.85U [°]** → 1.2 m/s 时 ≈ 21°，6 m/s 时 ≈ 12° | Fish 1993 |
| 羽化参数 | 0.35 ± 0.11 | Fish 1993 |
| 推进效率 | **0.81 ± 0.04（范围 0.73–0.91）**；三维面元法算真实尾鳍 0.83–0.92 | Fish 1993；Ayancik et al. 2020 |
| 尾鳍展弦比 | *T. truncatus* **3.9–4.7**；鲸豚整体 2.0–6.2 | Fish 1993/1998/2007 |
| 剖面 | **对称、无弯度**，钝圆前缘，类 **NACA 63-021** | Fish et al. 2007, Anat. Rec. 290:614（CT 扫描 19 个标本） |
| 厚度比 t/c | 20% 展向处 **0.218 ± 0.007**，到翼尖降到 0.139 | 同上 |
| 最大厚度位置 | **0.285 c**，沿展向基本不变 | 同上 |
| 前缘半径 | 0.032–0.046 c | 同上 |
| 后掠角 | 21.5°–35.4° | Ayancik et al. 2020 |

**两条必须标注的空白：**

1. **海豚的沉浮–俯仰相位角，文献里查不到实测值。** Fish 1993/1998、Rohr & Fish 2004、Fish & Rohr 1999 都只报羽化参数，不报相位。所以 90° 是**从翼型实验借来的工程假设，不是抄自生物**，必须当可调量。
2. **攻角时程是前载的，不是正弦。** Fish 1993 原话：攻角在行程起始时迅速上升，**在前 1/3 行程内达到峰值**，行程末端降到与前进方向平行。这更接近平台形，而不是正弦。

## 四、展弦比与平面形状：一个硬约束

- 海豚尾鳍 AR 3.9–4.7；Ayancik 2020 的三维面元法确认"**AR 越高效率越高**"；Fish 2004 给出上限：**"AR above 8–10 provides little further advantage."**
- **我们的展开态折扇 AR = 2.87，低于海豚。**
- 更关键的是：**扇形这个平面形状本身有 AR 上限。** 圆扇形的 AR = 8sin²(θ/2)/θ，对 θ 求极值得 tan(θ/2) = θ，解出 θ ≈ 133.6°，**AR_max = 2.90**。我们的 120° 已经取到 2.87，是上限的 99%。
- **结论：折扇形状的展弦比天花板就是 2.9，靠调开合角提不上去。要达到海豚的 4–5，必须换平面形状（不是圆扇形）。**

**后掠角不用追。** Zurman-Nasution et al. 2021（J. R. Soc. Interface 18:20210174）用三维仿真扫遍生物后掠角范围，**后掠角与推进性能的最大相关系数只有 0.043**，结论是后掠不决定性能。Karpouzian 1990 的月牙尾最优也是**很宽的平台**（AR 10 时 0.5 < K < 1.0 内 η > 0.80），且其主要价值是"在尾柄行程受限时仍能保持高效率"——即**后掠可以替代沉浮幅值**。没有任何可验证的文献给出"月牙形比三角形好百分之多少"。

## 五、波形整形：我之前的判断错了

我用准定常模型扫描后说"波形整形在升力型里没用"。**这个结论是错的**，因为准定常模型看不见 LEV 的时序，而波形整形的收益恰恰全在那里。实验文献：

- **Hover, Haugsdal & Triantafyllou 2004, JFS 19:37**（Re ≈ 3×10⁴）：直接规定攻角时程，比较 harmonic / square / sawtooth / **cosine** 四种。**cosine 型 α(t) 在 η = 0.64 下给出 C_T = 0.624，而 harmonic 型同样 η = 0.64 时只有 C_T = 0.175**——注意这是两个不同工况点（cosine 在 St 0.35/α 20°，harmonic 在 St 0.25/α 10°），所以准确的说法是：**cosine 型攻角把高效率区间延伸到了更高的 St 和更大的攻角，那里推力高 4 倍。**方波型反而更差（η 0.60）。
- **Read 2003**：在沉浮里加**三次和五次谐波**，运动本身只改变 <6%，但阻止了高 St 下 α(t) 的劣化，**St = 0.60 时 C_T 从 0.58 涨到 1.21**，效率平台保持。
- **Van Buren et al. 2017, PRF 2:053101**：把**位置波形**方波化，给定 St 下推力最多 **4 倍**，但"**要最高效还是正弦最好**"。
- **Qi et al. 2019, PLoS ONE 14:e0218832**（URANS, Re = 4.2×10⁴）：梯形俯仰只在俯仰幅值**低于**正弦最优时有用（θ₀ = 40° 时效率 +46%，θ₀ = 60° 时 −9%）。

**归纳：把位置波形方波化 → 换推力、丢效率；把攻角时程整形成平台（cosine 型）→ 把高效区推到更高 St，同效率下推力翻几倍。而海豚做的正是后者（前载平台型攻角）。三者指向同一个结论。**

## 六、翻译到 BODY2 的设计表

| 参数 | 文献最优 | 现在的方案 | 结论 |
|---|---|---|---|
| 展弦比 AR | 海豚 3.9–4.7；>8–10 无增益 | 折扇展开 **2.87** | **扇形上限 2.90，已到顶**。要到 4–5 必须换平面形状 |
| 剖面厚度 t/c | 生物 0.20–0.22；翼型正典 NACA 0012 = 0.12 | 平板 5.6/42 = **0.133** | 厚度没问题 |
| 前缘 | 钝圆，半径 0.032–0.046 c | **方边平板** | **倒圆前缘（R ≈ 1.3–2.8 mm）——最便宜的一项改进** |
| 后掠 | 20–35°，但相关性仅 0.043 | — | 不用追 |
| St | 效率 0.25–0.35（海豚 0.26）；推力 0.6 | **0.28** | 效率目标已对；**推力目标要到 0.5–0.6** |
| α_max | 生物 10–22°（~15）；翼型 15–25°（~20） | **12.4°** | **偏低，提到 18–20°**（χ 从 0.70 降到 0.50–0.60） |
| h₀/c | 0.75–1.0 | 35/42 = **0.83** | 已对 |
| 相位 ψ | 75–90° 俯仰领先（**海豚未测**） | 90° | 保留，但当扫描量，扫 70–110° |
| 俯仰轴 | 惯例 1/3 弦；分歧大，无系统扫描 | 1/4 弦 | **当扫描量**：LE / 0.25c / 0.33c |
| α 时程 | **前载平台型**（峰值在前 1/3 行程） | 正弦 | **必须进矩阵** |
| 预期 η | 海豚 0.80–0.91；2D 翼型 0.64–0.87 | — | 三维、低 Re、平板，预期低于这些 |

**一个方向性判断：生物优化的是效率（动物受耐力限制），而 BODY2 大概率受推力限制。** 所以不能盲抄 St = 0.26。文献两端都给了：效率最优 St 0.25–0.30，推力最优 St 0.6（η 掉到 0.43–0.49）。**先决定优化目标，再选 St。**

## 七、建议的 CFD 矩阵（按文献定，不按我的准定常扫描）

基准工况：h₀/c = 0.83、ψ = 90°、俯仰轴 1/4 弦、展开态折扇、U = 0.25 m/s。

1. **验证算例**：NACA 0012、AR 6、俯仰轴 1/3 弦、h₀/c = 0.75、α_max = 20°、ψ = 75°、St = 0.30 → 对 Anderson 1998 的 η = 87%、C_T ≈ 0.67。**先过这一关再信自己的数。**
2. **St 扫描**：0.25 / 0.35 / 0.50 / 0.60，α_max 固定 20°（即 χ 随 St 调整）
3. **α_max 扫描**：12° / 20° / 30°，St 固定 0.35
4. **相位扫描**：ψ = 75° / 90° / 105°
5. **俯仰轴**：0.25c / 0.33c
6. **波形**：正弦 α vs 前载平台型 α（cosine 型），在 St = 0.50 上比——**低 St 上比不出差别，必须在高 St 上比**
7. **前缘倒圆** vs 方边平板，同运动学

前两项是必须的，3–7 按时间排。

## 参考文献

- Anderson J.M., Streitlien K., Barrett D.S., Triantafyllou M.S. (1998) *J. Fluid Mech.* 360:41–72. DOI 10.1017/S0022112097008392
- Read D.A., Hover F.S., Triantafyllou M.S. (2003) *J. Fluids Struct.* 17(1):163–183. DOI 10.1016/S0889-9746(02)00115-9
- Triantafyllou M.S., Triantafyllou G.S., Gopalkrishnan R. (1991) *Phys. Fluids A* 3:2835. DOI 10.1063/1.858173
- Taylor G.K., Nudds R.L., Thomas A.L.R. (2003) *Nature* 425:707–711. DOI 10.1038/nature02000
- Hover F.S., Haugsdal Ø., Triantafyllou M.S. (2004) *J. Fluids Struct.* 19:37–47. DOI 10.1016/j.jfluidstructs.2003.10.003
- Floryan D., Van Buren T., Rowley C.W., Smits A.J. (2017) *J. Fluid Mech.* 822:386–397. DOI 10.1017/jfm.2017.302
- Van Buren T., Floryan D., Quinn D., Smits A.J. (2017) *Phys. Rev. Fluids* 2:053101. DOI 10.1103/PhysRevFluids.2.053101
- Qi X., Zhai Y., Li Z., Peng D. (2019) *PLoS ONE* 14(7):e0218832. DOI 10.1371/journal.pone.0218832
- Fish F.E. (1993) *J. Exp. Biol.* 185:179–193. DOI 10.1242/jeb.185.1.179
- Fish F.E. (1998) *J. Exp. Biol.* 201:2867–2877
- Rohr J.J., Fish F.E. (2004) *J. Exp. Biol.* 207:1633–1642. DOI 10.1242/jeb.00948
- Fish F.E., Beneski J.T., Ketten D.R. (2007) *Anat. Rec.* 290:614–623. DOI 10.1002/ar.20546
- Fish F.E. (2004) *IEEE J. Oceanic Eng.* 28(3):605–621
- Ayancik F., Fish F.E., Moored K.W. (2020) *J. R. Soc. Interface* 17:20190655. DOI 10.1098/rsif.2019.0655
- Karpouzian G., Spedding G., Cheng H.K. (1990) *J. Fluid Mech.* 210:329–351
- Zurman-Nasution A.N., Ganapathisubramani B., Weymouth G.D. (2021) *J. R. Soc. Interface* 18:20210174. DOI 10.1098/rsif.2021.0174
- Lighthill M.J. (1970) *J. Fluid Mech.* 44(2):265–301. DOI 10.1017/S0022112070001830

**未能打开原文的**：Chopra 1976 / Chopra & Kambe 1977（Fish 所用的升力面理论）、van Dam 1987 Nature 325:435（月牙翼效率）。引用其中数字前需自行核对。

## 八、算例矩阵的运动学图示（2026-09-18 补）

`fig_cfd_matrix.png/.pdf`（频闪总览）、`cfd_matrix_demo.mp4`（35 s 演示，七个场景实时拍动）。
生成脚本：`cfd_matrix_kin.py`（共用运动学）、`fig_cfd_matrix.py`、`make_cfd_matrix_anim.py`。

把七个算例的运动学全部反解出来（给定 St 与 α_max，反解俯仰幅值 θ0 与羽化系数 χ），**在开算之前就暴露了两个舵机约束**：

| 算例 | f [Hz] | χ | θ0 | 俯仰峰值角速度 | 7465W 余量 |
|---|---|---|---|---|---|
| 验证（Anderson 1998） | 1.19 | 0.64 | 28° | 206 °/s | 4.0× |
| St 0.25 | 0.90 | 0.48 | 18° | 102 °/s | 8.0× |
| St 0.35 | 1.26 | 0.58 | 28° | 219 °/s | 3.8× |
| St 0.50 | 1.79 | 0.69 | 40° | 446 °/s | 1.8× |
| **St 0.60** | 2.15 | 0.77 | 48° | **642 °/s** | **1.3×** |
| α_max 12° / 20° / 30°（St 0.35） | 1.26 | 0.77 / 0.58 / 0.37 | 37 / 28 / 18° | 289 / 219 / 140 °/s | 2.8× / 3.8× / 5.9× |
| ψ 75° / 90° / 105°（St 0.35） | 1.26 | 0.76 / 0.58 / 0.76 | 36 / 28 / 36° | 285 / 219 / 285 °/s | 2.9× / 3.8× / 2.9× |
| 强制正弦 α（St 0.50） | 1.79 | 0.69 | 40° | **854 °/s** | **1.0×** |
| 方波型 α（St 0.50） | 1.79 | 0.69 | 40° | **973 °/s** | **0.8×** |

1. **St = 0.60（纯推力最优点）只剩 1.3× 舵机余量**，基本顶到 7465W 上限。想走"推力优先"路线必须先换舵机，否则扫描扫不到最优点。
2. **在 St = 0.50 上做任何 α 波形整形都顶满或超出舵机**（强制正弦 854 °/s、方波 973 °/s）。波形整形不是免费的 —— 要么把整形放到更低的 St，要么换更快的舵机。这一条必须在开算前定。

另有一条容易被忽略的观察：**正弦俯仰在高 χ 下 α 时程本身已经接近平台型**（St 0.50、χ 0.69 时 α 呈带缺口的平顶波）。所以算例 ⑥ 的正确对照不是"正弦 vs 平台"，而是三选一：正弦俯仰 θ（现状）/ 强制正弦 α / 方波型 α。矩阵已据此修正。

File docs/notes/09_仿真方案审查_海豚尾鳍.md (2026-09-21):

---
title: 09 · 海豚尾鳍型仿真方案审查 —— 漏洞清单与新方法
date: 2026-09-18
status: review
---

# 09 · 海豚尾鳍型仿真方案审查：漏洞清单与新方法

对象：`08_仿生最优_海豚尾鳍与拍动翼.md` 里定下的七算例矩阵（`fig_cfd_matrix.png`），以及之前几轮对话里累积的假设。方法：把每条假设拿回文献里核，能查到数的给数。

**一句话结论：矩阵本身没算错，但它回答的是"拖曳水池里一块孤立翼型的最优 St 是多少"，而不是"BODY2 能不能用尾鳍游到 0.25 m/s、该怎么动"。两者之间隔着四件被跳过的事：整机阻力平衡、翼的几何（截面/平面形/支杆）、自由面、四桨干涉。其中第一件会直接推翻"St 取 0.25–0.35"这个前提。**

---

## 一、漏洞清单（按严重度排序）

| # | 漏洞 | 严重度 | 文献依据 | 后果 |
|---|---|---|---|---|
| 1 | **把 St 当输入。** 自航（self-propelled）时 St 是输出，由 Lighthill 数 Li = C_D·S_wet/S_foil 决定 | ★★★★★ | Moored & Quinn 2019；Ayancik 2020；Eloy 2012；Floryan 2018 PNAS | 整个"St 扫描"回答不了机器人的问题 |
| 2 | **没算整机阻力。** 4 条圆柱腿的阻力约是船体的 20 倍 | ★★★★★ | 本文 §二 估算 | 决定了 St 落在 0.3 还是 0.6，即决定舵机够不够、效率高不高 |
| 3 | **翼截面：方边平板 + 钝尾缘（t/c 13%）**。厚度本身不是问题，钝尾缘是 | ★★★★ | Ashraf 2011；Kelly 2023 | 钝尾缘卡门涡（~13 Hz）与反卡门涡街对冲；尖尾缘是效率前提 |
| 4 | **支杆（peduncle）没进模型。** 50 mm 圆柱杆正好在翼前缘上游 | ★★★★ | Gopalkrishnan 1994；Beal 2006；Khan 2023（均为有间距圆柱，零间距支杆无文献） | 翼在自己支杆的尾迹里工作，LEV 形成被破坏，CFD 必须带杆 |
| 5 | **验证算例选错。** Anderson 1998：AR 6 + 端板 ≈ 二维、Re 4×10⁴、C_T 只在图里、87% 同装置后来只做到 71–73% | ★★★ | Read 2003；Schouveiler 2005；Smits 2019 JFM | 验证不覆盖本项目的 Re 10⁴ 与 AR 2.9；目标值本身不可靠 |
| 6 | **自由面被刚盖掉了。** 翼在水面下约 1 弦，τ = 2πfU/g ≈ 0.20–0.29 正落在 Cleaver 2013 的推力衰减带 | ★★★ | Cleaver 2013；Filippas 2014；Zheng 2024 | 推力误差 5–20% 量级，方向为负 |
| 7 | **四桨干涉。** 前后桨间距 5–7 弦：后桨推力可在 0–2× 单桨之间摆动，取决于相位 | ★★★ | Muscutt 2017；Boschitsch 2014；Kurt & Moored 2018 | 步态相位是一阶设计量，单桨最优不能直接搬到整机 |
| 8 | **折扇几何是上一代设计的遗物。** 升力型没有回程，不需要折叠；AR 上限 2.90 的证明因此失去意义 | ★★★ | — | 平面形状可以自由选 |
| 9 | **低 AR 的推力亏损没计入。** AR 2.9 的环量项按 AR/(AR+2) = 0.59 折算 | ★★ | Ayancik 2022；Lagopoulos 2023 | 效率几乎不受影响，但推力打六折，直接影响 #2 的平衡 |
| 10 | **"二维先筛"对扇形平面不成立。** 弦长沿展向变化，没有二维截面可代表 | ★★ | — | 方案 C 只在换成矩形/梯形平面后才可用 |

另外几条我之前说过、现在要收回的话：

- "C_T ≈ 0.67"：来源是模型从图上读的，二次核对失败。**已从图里删除。**
- "87% 过不了后面全作废"：说过头。同一装置后来两篇的峰值是 71.5% / 73%，2D URANS 对 Schouveiler 能做到 60 vs 61%（Lampropoulos 2016）。**验证目标应换成 Schouveiler 2005 那个带误差棒的点。**
- "尖端朝前的三角形对 LEV 不利"：直觉判断，文献相反——凸形宽尾缘比方尾缘多 15% 推力（Van Buren 2017），梯形（前窄后宽）比矩形多 45% 推力、效率相当（Fernández-Gutiérrez 2021）。**扇形的"前窄后宽"方向是对的，只是前缘不该收成一个点。**
- "薄一点更好"：错。Re 2×10⁴ 时 NACA0020–0030 的推力和效率是 0006 的 3–4 倍（Ashraf 2011）；Re 10⁴ 最优 t_max = 0.21c、位于 0.30c（Kelly 2023）——**和海豚尾鳍截面（0.218c，在 0.285c）几乎一致**。13% 厚度没问题，问题只在方边。

---

## 二、漏洞 1 + 2：为什么 St 不能先定

### 自航的逻辑链

巡航时推力 = 阻力：T(f, h₀, θ₀; U) = D(U)。推力和阻力都 ∝ U²（一阶），所以 **U 从平衡里消掉了，剩下的是一个几何量决定工作点**：

**Li ≡ C_D·S_wet / S_foil，　St_op ≈ 0.75·Li^(1/3)**（Eloy 2012 对 53 种动物的拟合）

然后速度由频率给：U = 2f·h₀/St_op。**想游得快只能提频率，而频率顶着舵机。** 这就把"舵机速率"和"整机阻力"两个约束连成了一条线。

Moored & Quinn 2019 原话："In self-propelled swimming, controlling the Lighthill number is crucial in controlling k and the Strouhal number of a swimmer and, subsequently, in maximizing the efficiency." Ayancik 2020："the reduced frequency and the Strouhal number become outputs, since the swimming speed is unknown a priori."

### BODY2 的阻力预算（估算，待 CFD/实测替换）

M3 船体：LWL 233 mm、B 99 mm、T 38 mm、排水 385 cm³ → 湿面积 ≈ 250 cm²，Re_L = 5.8×10⁴（层流），Fr_L = 0.17（兴波可忽略）。

| 项目 | 阻力 @ 0.25 m/s | 说明 |
|---|---|---|
| 船体 | **≈ 6 mN** | Blasius Cf 0.0055 × 形状因子 1.3 |
| 4 条腿，圆柱 Ø10 × 80 mm 湿长，Cd 1.0 | **≈ 100 mN** | 是船体的 **18 倍** |
| 4 条腿，整流罩 Cd 0.3 | ≈ 30 mN | |
| 4 条腿，整流罩 Cd 0.15 | ≈ 15 mN | |

四桨可得推力（2D C_T 0.3–0.5 × AR 修正 0.59 × q·S）：**41–68 mN**。

| 腿的形态 | D_total | Li | St_op | 每桨需 C_T | 结论 |
|---|---|---|---|---|---|
| 圆柱杆 | 106 mN | 0.46 | **≈ 0.58** | 0.46 | 高效区推不动；被迫到 St 0.6 → 舵机 1.3× 余量、η 掉到 0.4 |
| 整流罩 Cd 0.3 | 36 mN | 0.15 | ≈ 0.40 | 0.15 | 可行 |
| 整流罩 Cd 0.15 | 21 mN | 0.09 | ≈ 0.34 | 0.09 | **落在海豚区间** |

**这张表的含义比七算例矩阵全部加起来都大：腿做不做整流罩，决定了尾鳍方案是"高效区里游"还是"顶着舵机上限硬推"。** 所有运动学优化加起来的收益都不到一个数量级；把腿的 Cd 从 1.0 降到 0.15 是 5 倍。

（Eloy 的拟合来自波动式游泳动物，用在四桨机器人上是外推；数量级可信，小数点后一位不可信。）

---

## 三、漏洞 3–4：翼的几何

### 截面

| 特征 | 现状 | 文献最优（Re 10⁴） | 改法 |
|---|---|---|---|
| 最大厚度 | 13%，均匀 | **21% c，位于 0.30 c**（Kelly 2023，η 比 NACA0012 高 15%） | 前厚后薄 |
| 前缘 | 方边 | 圆，R ≈ 0.03–0.05 c | 倒圆 1.3–2 mm |
| 尾缘 | **方边 5.6 mm** | 尖（"thicker leading-edge and sharper trailing-edge makes for a more efficient foil"） | 收尖到 ≤ 0.5 mm |

钝尾缘的害处可以直接估：尾缘涡脱落频率 ≈ 0.2·W/t = 0.2 × 0.37 / 0.0056 ≈ **13 Hz**，比拍动频率高一个量级，在尾迹里叠一串小涡，直接消耗本该形成反卡门涡街的能量。

海豚截面（t/c 0.218 在 0.285c，前缘半径 0.032–0.046c，尾缘尖）就是 Kelly 2023 的最优解——生物和数值在这一点上完全重合，照抄即可，不需要扫。

### 平面形

折扇的理由（回程折叠）在升力型里不存在。可以按文献直接定：

- **前窄后宽**（fish-tail 型）：梯形前缘宽 ≈ 0.5–0.6 展，凸弧尾缘（Van Buren 2017 +15%；Fernández-Gutiérrez 2021 +45%）
- AR 3–4：Lagopoulos 2023（Re 8500）：C_T 到 AR 4 才饱和，η 对 AR 2–8 几乎不敏感 → **AR 4 是推力性价比拐点**
- 后掠角：20→40° 只让 η 变 −3 到 −6%（Zurman-Nasution 2021），次要
- 展长上限由左右腿间距定（船宽 99 mm ≈ 2.4 弦 → 左右干涉可忽略，Gungor 2022 的 d* ≤ 1–2c 判据）

**如果仍要保留划水（加速/机动）模式**（Baines 2022：划水加速度高、拍动巡航省），折扇才有意义，但那是另一个设计问题，不该混进尾鳍 CFD 里。

### 支杆

零间距支杆没有文献，只有"上游圆柱尾迹打到翼上"的研究：St 0.6 时推力 −13%（Khan 2023），效率强烈依赖涡与翼的相位（Gopalkrishnan 1994）。三条要求：**支杆做流线型截面；CFD 必须把杆算进去；杆越短越好**（现在 50 mm 杆 + 42 mm 翼，杆比翼还长）。

---

## 四、漏洞 5–7：环境与验证

### 验证改成两层

| 层 | 算例 | 为什么 |
|---|---|---|
| 二维/高 AR | **Schouveiler 2005**：NACA0012、c 0.1 m、U 0.4、Re 4×10⁴、h₀/c 0.75、轴 1/3c、ψ 90°、St 0.25、α_max 15° → **η 0.73 ± 0.04、C_T 0.32 ± 0.01** | 有误差棒的数；同装置 Anderson 只给 87% 一个数、C_T 在图里 |
| 三维/低 AR/低 Re | **Van Buren 2017 PRF**：AR 1 矩形俯仰板、Re 10⁴、St 0.4、方尾缘 η ≈ 0.10（凸尾缘 +15% 推力） | Re 和 AR 都在本项目区间；实验数据 |
| 备选 | Lagopoulos 2023：NACA0016、Re 8500、St 0.4、AR 2–8（数值，非实验） | 直接覆盖 AR 2.9 |

Anderson 的 87% 保留作参考上限，不作为通过判据。

### 自由面

Fr_c = 0.39，τ = 2πfU/g = 0.20（f 1.26）–0.29（f 1.79）。Cleaver 2013：τ ≈ 0.25 附近推力衰减，d/c > 2 才可忽略。翼顶到水面的距离：−85 + 35 = −50 mm ≈ 1.2 弦。**必须至少跑一个 interFoam 对照，或者把腿加长到 d/c ≥ 2。**

### 四桨相位

前后桨间距 0.2–0.3 m = 5–7 弦，刚好在 Muscutt 2017 测的 5c 边缘。后桨推力 0–2× 单桨，最优相位随间距线性移动（脊线倾斜）——**也就是最优步态相位随速度变**，因为尾迹对流距离 = U·T。这条要写进控制器，不是固定步态。

---

## 五、新方法：三层保真度 + 自航闭环

原方案是"一层 LES 扫 16 个变体"，8 核跑不完，且扫的变量（St）不是自由变量。改成：

### 第 0 层：阻力预算（先做，一周内）

- 船体 + 腿（两种腿：圆柱 / 整流罩）稳态 RANS，`simpleFoam`，U = 0.15 / 0.25 / 0.35 m/s → D(U)
- 或者更快：拖曳实测（M3 船体已可打印）
- 产出：Li 和 **每桨需 C_T(U)** 曲线。这一步决定后面所有事。

### 第 1 层：三维非定常面元/涡格法（分钟级，扫全矩阵）

- 工具：**PteraSoftware**（Python，MIT，自由尾迹 UVLM，"most unsteady simulations take under a minute"）或 Lehigh BEM-3D-Python；DUST 备选
- 补一项黏性阻力偏置 C_D（Floryan 2017 的形式：C_T = c₁St² + … − C_D），偏置用第 2 层的 2–3 个点标定
- 输入：翼几何（梯形 + 厚截面）、h₀、θ₀、ψ、f、支杆
- 输出：C_T(f, θ₀, ψ)、C_P、η 的整张地图
- **与第 0 层闭环**：对每组运动学解 T = D → U、St_op、需要的舵机速率；淘汰所有超出 820 °/s 的点
- 这是 Ayancik/Moored 做真实海豚尾鳍用的同一类方法，效率预测 83–92%（无黏上限）

### 第 2 层：OpenFOAM 三维 LES（3–4 个点）

- 只算第 1 层选出的最优点 + 验证两例 + 一个自由面对照
- **带支杆、带正确截面**
- 湍流：WALE LES；网格细化盒沿尾迹拉长 ≥ 3 个涡波长（U·T ≈ 4.7 弦/周期）
- 取 8–10 个周期；以 η（不是 F̄x）做网格无关性判据
- 8 核上每个 1–2 天可接受；集群批下来再补 St 扫描

### 第 3 层（可选，论文加分项）：整机四桨

- 两桨串列（前 + 后）LES，扫 3 个相位 → 验证第 1 层的干涉预测
- 与 Wang 2025 的 F̄x/4F̄SL 指标同框

---

## 六、修订后的算例表

| 序 | 层 | 内容 | 判据 |
|---|---|---|---|
| 0a | RANS 稳态 | 船体 + 圆柱腿，3 个 U | D(U)、Li |
| 0b | RANS 稳态 | 船体 + 整流罩腿，3 个 U | 同上；两者之差 = 整流罩的价值 |
| V1 | LES | Schouveiler 2005 点 | η 0.73 ± 0.04、C_T 0.32 ± 0.01 |
| V2 | LES | Van Buren 2017 AR 1 方尾缘板 | η ≈ 0.10 @ St 0.4 |
| 1 | UVLM | 全矩阵：f × θ₀ × ψ × 截面 × 平面形，自航闭环 | 可行域 + 最优点 |
| 2a | LES | 第 1 层最优点（带支杆、厚截面、尖尾缘） | C_T、η、涡结构 |
| 2b | LES | 同 2a，方边平板（旧几何） | 几何改进的收益 |
| 2c | interFoam | 同 2a，真实吃水 d/c ≈ 1.2 | 自由面损失 |
| 3 | LES | 前后两桨，3 个相位 | 后桨增益/损失 |

原七算例里保留的：ψ 扫描（海豚相位仍无实测）、α 波形（放到第 1 层扫）。删掉的：St 扫描（变成输出）、俯仰轴扫描（第 1 层顺手做）、前缘倒圆（直接采用最优截面，不再对照）。

---

## 七、一件不能再拖的事

**腿的截面。** 不管最后选尾鳍还是划水，只要腿是圆柱杆，Li ≈ 0.46 就把整机锁在 St 0.6 的低效区。整流罩是个机械问题，不是流体问题，但它是整个尾鳍方案成立的前提。建议在任何 CFD 之前先把腿的截面定下来。

## 参考文献（本次新增）

- Floryan D., Van Buren T., Smits A.J. (2018) *PNAS* 115(32):8116. DOI 10.1073/pnas.1805941115
- Floryan D., Van Buren T., Rowley C.W., Smits A.J. (2017) *J. Fluid Mech.* 822:386. DOI 10.1017/jfm.2017.302
- Eloy C. (2012) *J. Fluids Struct.* 30:205. arXiv 1102.0223
- Moored K.W., Quinn D.B. (2019) *AIAA J.* 57(9):3686. Inviscid scaling laws of a self-propelled pitching airfoil
- Moored K.W. (2018) *Comput. Fluids* 167:324. DOI 10.1016/j.compfluid.2018.03.045
- Ayancik F., Mivehchi A., Moored K.W. (2022) *AIAA J.* arXiv 2010.06618
- Smits A.J. (2019) *J. Fluid Mech.* 874:P1. Undulatory and oscillatory swimming
- Sentürk U., Smits A.J. (2019) *AIAA J.* 57(7). DOI 10.2514/1.J058371
- Schouveiler L., Hover F.S., Triantafyllou M.S. (2005) *J. Fluids Struct.* 20:949
- Lampropoulos N., Koubogiannis D., Belibassakis K. (2016) 11th HSTAM Congress
- Ashraf M.A., Young J., Lai J.C.S. (2011) *J. Fluids Struct.* 27:145
- Kelly J., Khalid A., Han P., Dong H. (2023) *J. Fluids Eng.* 145
- Van Buren T., Floryan D., Brunner D., Senturk U., Smits A.J. (2017) *Phys. Rev. Fluids* 2:014702
- Fernández-Gutiérrez D., van Rees W.M. (2021) *J. Fluid Mech.* 921
- Lagopoulos N.S., Weymouth G.D., Ganapathisubramani B. (2023) *Flow* 3
- Zurman-Nasution A.N., Ganapathisubramani B., Weymouth G.D. (2020) *J. Fluid Mech.* 904:A33；(2021) *J. R. Soc. Interface* 18:20210174
- Dong H., Mittal R., Najjar F.M. (2006) *J. Fluid Mech.* 566:309
- Buchholz J.H.J., Smits A.J. (2008) *J. Fluid Mech.* 603:331
- Cleaver D.J., Wang Z., Gursul I. (2013) *Exp. Fluids* 54:1491
- Filippas E.S., Belibassakis K.A. (2014) *Eng. Anal. Bound. Elem.* 41:47
- Zheng et al. (2024) *J. Fluid Mech.* Free-surface-induced ground effect for flapping swimmers
- Muscutt L.E., Weymouth G.D., Ganapathisubramani B. (2017) *J. Fluid Mech.* 827:484
- Boschitsch B.M., Dewey P.A., Smits A.J. (2014) *Phys. Fluids* 26:051901
- Kurt M., Moored K.W. (2018) *Bioinspir. Biomim.* 13:045002
- Gungor A., Khalid M.S.U., Hemmati A. (2022) *J. Fluid Mech.* 951:A37
- Gopalkrishnan R., Triantafyllou M.S., Triantafyllou G.S., Barrett D. (1994) *J. Fluid Mech.* 274:1
- Beal D.N. et al. (2006) *J. Fluid Mech.* 549:385
- Khan, Akhtar, Khalid (2023) arXiv 2410.23909
- PteraSoftware: github.com/camUrban/PteraSoftware；BEM-3D-Python: github.com/wcs211/BEM-3D-Python；DUST: public.gitlab.polimi.it/DAER/dust

**未能打开原文、数字需自核**：Sentürk & Smits 2019（AIAA 被挡）、Zhu-Liu-Yue 2006、Boschitsch 2014 摘要、Buchholz & Smits 2008 分 AR 表。

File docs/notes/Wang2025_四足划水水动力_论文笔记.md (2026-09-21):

---
type: paper
title: A Computational Study on the Hydrodynamics of Bio-Inspired Quadrupedal Paddling
institute: 华南理工大学 吴贤铭智能工程学院（通信作者 Yunquan Li、Ye Chen）；合作单位 北京大学力学与工程科学系
year: 2025
venue: Biomimetics 10(3), 148
paper_type: journal
doi: 10.3390/biomimetics10030148
status: read
topics:
  - 四足划水
  - 阻力型推进
  - 浸没边界法
  - 步态序列
  - 水动力矩与能耗
Annotator: Lu (Xiaotian Lu)
date_created: 2026-09-16
---

# A Computational Study on the Hydrodynamics of Bio-Inspired Quadrupedal Paddling

## 一句话结论

四足划水的总推力不是单腿推力的简单叠加——腿间干涉（Interferenz）几乎总是增益（F̄x / 4F̄SL = 1.00–1.87）；而缩短划水占空比 DR 换来的推力提升，必须用更大的横摇/纵摇/偏航力矩和不成比例增长的能耗去买。

## 研究问题

作者把问题拆成三问：

（I）推进推力如何被划水运动学参数——初始摆角 α₀、摆幅 β₀、划水相占空比 DR——影响？
（II）推力如何被不同的步态序列（trot、对角序 diagonal sequence、同侧序 lateral sequence）影响？
（III）水动力矩（Mx/My/Mz）与能耗如何被上述运动学参数和步态序列调制？

这三问的共同前提是：阻力型推进（drag-based）虽然效率不如身体波动和鳍摆的升力型推进（lift-based），但腿式两栖机器人为了陆上通过性只能接受这个效率损失，所以值得把这个"低效但必要"的机制算清楚。

## 工作缺口

- 此前对四足划水的受力分析基本都停在阻力公式 + 一个假定的 Cd 上，三维腿形和腿间相互作用被整体忽略。作者直言这类简化模型"易用但在实践中可能导致显著误差"。
- 已有的桨腿 CFD 研究（表 1：Zhang 2014 IBM 四腿、Chen 2021 Fluent 滑移网格两腿、Baines 2022 Fluent SIMPLEC 四腿）针对的是小龙虾、海狸式蹼足、海龟，模型与哺乳动物式四足划水形态差别很大。
- **步态序列这一维度此前完全没有被 CFD 研究过**——这是本文自我定位的核心空白。

## 核心贡献

1. 用自研并行三维尖锐界面浸没边界（sharp-interface IBM）求解器，系统扫描 α₀ × β₀ × DR = 3 × 3 × 3 的参数空间，并叠加三种步态，给出完整的单腿与四足对照数据集（表 2、表 3、表 4）。
2. 提出并命名三种阻力型推力生成模式：**Trotting Mode**（双峰，对角腿对交替贡献、且被另一对腿削弱）、**Hindering Mode**（M 形四峰，个体腿的推力被"前一条腿离开划水相进入回程"产生的诱导阻力咬掉一口）、**Separate Mode**（干净四峰，四腿在周期内均匀独立贡献）。
3. 定量给出腿间干涉增益指标 F̄x / 4F̄SL（表 3），证明四足推力普遍大于四倍单腿推力——干涉是增益而非损失。
4. 给出峰值推力时刻的构型规律：在给定 β₀ 下，t_pk 时刻上下肢的相对构型 γ_pk 完全相同，与 α₀ 和 DR 无关；而"前倾更多、上下肢更平"的构型一致对应更低的推力。
5. 给出代价表：trot 的 Mx、Mz 远小于对角序与同侧序；功率与 α₀ 无关、与步态序列（对角 vs 同侧）无关，只由 β₀ 和 DR 决定；DR 由 50% → 33% → 25% 时单周期做功 1.37 → 2.40 → 4.37 J。

## 方法

**几何与运动学.** 模型取自一台真实四足机器人：大腿 L₁ = 10.6 cm、小腿 L₂ = 12.0 cm、肢宽 W = 4.65 cm，前后腿距 L = 32 cm、左右距 D = 12.4 cm。腿被当作**刚性、无变形、无脚蹼**的杆，整机**系留**（tethered，来流 U = 0），采用单向耦合（流体不反过来使结构变形）。角度轨迹 α(t)、γ(t) 由真狗游泳视频重建。

**参数.** α₀ ∈ {60°, 70°, 80°}，β₀ ∈ {20°, 30°, 40°}，DR ∈ {50%, 33%, 25%}。注意周期 T 只由 β₀ 决定（0.8 / 1.2 / 1.6 s），DR 变小意味着**在同一周期内把划水段压得更短、更快**：小腿端平均速度 Ū 从 0.42–0.64 m/s 一路升到 0.84–1.34 m/s。

**数值.** 不可压 N–S，笛卡尔网格 290 × 160 × 160，桨腿附近加密至 Δx = 0.25 cm，Δt = 2 × 10⁻⁴ s，每腿表面 29 940 个三角元。峰值 Re ~ O(10⁴)（trot 3.0 × 10⁴，DR 25% 达 6.2 × 10⁴）**按层流处理，不引入湍流模型**。域分解 256 个子域、256 核并行。取第 5 个周期的结果以摆脱静止初场的影响。附录 A 给出网格（Δx = 0.30 / 0.25 / 0.20 cm）与时间步（3 / 2 / 1 × 10⁻⁴ s）无关性验证。

**无量纲化.** 力除以 ρ U₀²W²，其中 U₀ = 0.42 m/s、W = 4.65 cm——换算下来 **1 个无量纲力单位 = 0.381 N**，这一步对读懂表 2 至关重要。另有推力系数 CT = 2F̄x,avg /(ρ Ū²L₂W) 和功率系数 P̄avg（除以 ρ Ū³L₂W/2）。

## 最强证据

**表 3（F̄x / 4F̄SL）配合图 5a 的 M 形波形。**

表 3 是全文信息密度最高的一张：在 27 个（α₀, β₀, DR）组合里，四足平均推力与"四倍单腿推力"的比值几乎全部大于 1，最高达 1.87（80°, 20°, DR 25%），唯一的例外是 (60°, 20°, 25%) = 1.00。它一次性证明了两件事：腿间干涉在阻力型四足划水里是**净增益**；而这个增益**不是线性可预测的**——同样把 DR 从 33% 压到 25%，(80°,20°) 从 1.52 升到 1.87，(60°,20°) 却从 1.20 掉回 1.00。这就否定了"整机 = 单腿叠加 + 相位移"的简化模型，也正是作者对既有 Cd 假定模型的正面反驳。

图 5a 则是 Hindering Mode 的直接视觉证据：单腿推力波上清晰地被前一条腿进入回程时的诱导阻力"咬"出一个缺口，形成 M 形。这个波形不是统计量，而是机制本身的指纹。

## 对比与消融

- **Baselines：** 单腿（SL）划水。全文每一张四足力曲线上都叠了对应的单腿曲线，这是贯穿始终的基准线，也使 F̄x / 4F̄SL 这个指标得以定义。
- **Ablations：** 三维参数网格 α₀ × β₀ × DR（3×3×3），再乘以三种步态；力、力矩、功率三套输出。
- **被单独验证的模块或因素：**
  - 腿间干涉：通过 F̄x / 4F̄SL 与单腿数据直接相减/相除，单独隔离出来。
  - 步态序列对功率的影响：证明对角序与同侧序功率曲线完全重合 → 序列不影响能耗，只影响力矩相位。
  - 初始摆角对功率的影响：证明 P(t) 与 α₀ 无关（图 11a,b）→ α₀ 是"白拿"的推力参数，减小 α₀ 提高推力不增加能耗。这是全文对工程最直接有用的一条。
  - 数值可信度：附录 A 的网格与时间步无关性。

## 局限与疑问

**我不相信或不确定的地方：**

- **"DR 越小推力越大"其实主要是桨速的收益，不是占空比的收益。** DR 从 50% 压到 25% 的同时，Ū 从 0.42 涨到 1.34 m/s。推力 ∝ v²，涨是必然的。用作者自己按 Ū² 归一的 CT 来看反而是反向的：(β₀ = 20°, α₀ = 60°) 的 CT 随 DR 50 → 33 → 25 单调下降 0.24 → 0.19 → 0.18。也就是说单位"速度平方"换来的推力是在变差的。论文把这一点放进了表 2 却没有讨论。
- **能耗代价被轻描淡写了。** 取同一组 (α₀ = 80°, β₀ = 40°)：四足平均推力 1.90 → 2.89 → 4.49（×2.36），而单周期做功 1.37 → 2.40 → 4.37 J（×3.19）。每焦耳产生的推力掉了约 26%。论文只写了 "additional energy expenditure becomes inevitable"，全文没有任何效率指标（无 Froude 效率、无推力–功率曲线），因此"最优 DR 在哪"这个最有工程价值的问题并没有被回答。（需要注意这个对比里步态也从 trot 换成了对角序，不是纯粹的 DR 消融。）

**可能存在的替代解释：**

- Hindering Mode 的 M 形缺口，作者归因于"前一条腿进入回程产生的诱导阻力"。但同一时刻也正是当前腿自身尾涡脱落与桨面失去附加质量支撑的时刻。论文用的是压力云图的定性观察，没有做"去掉前一条腿"的对照算例，所以两种解释无法区分。
- 四足推力大于四倍单腿，也可能部分来自系留条件下腿群整体在流场中建立的诱导回流（一种"集体加速尾流"效应），而不只是两两之间的干涉。

**实验还不充分的地方：**

- **完全没有实验校核。** 把表 2 的无量纲值换算成有量纲：单腿平均推力 0.29 N（DR 50%）到 0.90 N（DR 25%），四足对角序可达 3.57 N。而 Qu 2025 对真实两栖机器狗的实测是单腿 0.12–0.17 N、整机 0.69–0.92 N，低了 2–5 倍。两者机器不同、尺度不同，不能直接判谁对，但一篇纯 CFD 的论文给出高出实测一个档位的量级而不做任何标定，是需要警惕的。
- 每个参数只取 3 个离散值，作者自己承认这是局限，无法给出 F̄x / 4F̄SL 与运动学参数的关系式。

**作者隐含的假设：**

- 腿是刚性的、单向耦合的（水不使结构变形）；
- Re 达到 6 × 10⁴ 仍按层流处理；
- 无自由面、无机体、无来流；
- **回程与划水的迎流面积完全相同**——这是最关键、也最少被明说的一条假设。

## 与我的研究的关系

### 已经被这篇论文做掉的内容

- **步态序列扫描。** trot / 对角序 / 同侧序对整机推力与力矩的定性影响已经做完，而且对角序与同侧序被证明几乎等价（力曲线相同、功率完全相同，只差 T/4 相位）。我进入整机阶段后不需要重做这一层，可以直接采用其结论：优先稳定性选 trot（Mx、Mz 显著更小），优先推力选对角/同侧序 + 小 DR。
- **"腿间干涉是增益"这个基本判断。** F̄x / 4F̄SL ≥ 1 让我可以放心地先在单腿层面做轨迹优化，把整机耦合当作一个 1.0–1.9 的正向系数，而不是一个先验的惩罚项。这对我目前"先求单腿最优轨迹、再设计结构"的路线是一条直接的授权。
- **α₀ 与构型的规律。** 初始摆角越小推力越大、且不增加功率；峰值推力时刻的上下肢相对构型只由 β₀ 决定。对我的"结构无关目标轨迹"而言，这意味着划水段应尽量贴近水平、避免前倾构型——与我 04 号轨迹（z = −85 mm 的水平直线行程）的取向一致。

### 可以直接借用的方法

- **F̄x / 4F̄SL 指标。** 等我做到四腿，直接用它衡量我的方案的干涉增益，与本文同框可比。
- **无量纲化方案。** 力 / ρU₀²W²、CT = 2F̄x,avg /(ρŪ²A)、P̄avg。我目前一直用有量纲 mN 报结果，补上 CT 一列后就能与本文表 2 以及 Qu 2025 放在同一张图上比较——这是审稿人一定会问的。
- **附录 A 的数值可信度呈现方式。** 三条网格曲线 + 三条时间步曲线叠在同一张 F̄x(t) 图上，简洁有力。我的 overset 算例应当对 V3trap 补同样的两张图。
- **力矩口径。** Mx/My/Mz 绕同一原点在流固界面上积分，并观察到 My,avg 在所有步态下恒为负。这与我 V3trap 的 |M̄y| = 36.7 mN·m 是同一套讨论口径。

### 它留下的研究空白

这四条正好是我在做的事，可以逐条对应写进我的引言：

1. **回程自由度完全缺失。** 本文的腿在回程和划水时迎流面积完全相同，所以回程阻力不可避免且随回程速度平方增长——全文所有"回程是负贡献"的结论都建立在这个假设上。我的第一套（120° 折扇收拢到 12 mm，面积比 27%）和第二套（刚性板绕桨杆羽化 90°，面积比 13%）要消掉的正是这一项。我的 C6 系列已经量到：只把回程面积收小，净推力 49.3 → 56.7 mN（+15%），回程段相平均力从 −19.3 mN 改善到 −5.9 mN。本文没有、也不可能有这个维度。
2. **速度律（Geschwindigkeitsgesetz）不是设计变量。** 本文的 α(t) 是从狗的视频重建的一条固定曲线，DR 只把它整体缩放。我把速度律本身当成可设计的对象：在同样峰值角速度和 50° 摆幅下，梯形律相比余弦律的 ∫v²dt 高 18%；CFD 实测 V3c12 56.7 → V3trap 75.0 mN（+32%）。（诚实地说，这 +32% 里不只是速度律——V3trap 同时把 T 从 0.81 缩到 0.72 s、DUTY 从 0.45 降到 0.382，所以它和本文的 DR 扫描犯的是同一类混淆，只是方向相反。这一点我在自己的报告里需要拆干净。）
3. **开合/羽化时机没有对应自由度。** 我的两态合成扫描给出最优切换点 τ_o = −0.06、τ_c = 0.33（= 划水段的 82–86%），并且两个切换点都对应同一个临界桨速 ≈ 0.20–0.26 m/s ≈ 0.7 v_max。本文没有可切换的状态，自然没有这个维度。
4. **最优 DR 的判据缺席。** 本文只得到"DR 越小推力越大"的单调趋势，止步于此。我这边有一个可解释的判据：最优占空比由回程与划水的有效阻力比 a_eff = (F_rec/F_pw)(v_p/v_r)² 决定，我的三种构型分别是 a_eff = 0.10（回程全开）/ 0.03（收拢 12 mm）/ 0.013（羽化板）。a_eff 越小，理论最优 DUTY 越大；但真实系统里回程速度受舵机限速，DUTY 最终落在由路径长度比给出的 0.4–0.5。本文的 a_eff 固定且偏大，所以它看到的只是这条曲线上的一段。

### 对机构、控制、算法或实验的启发

- **作动器量级的对照。** 本文明确点名 GXservo-X50（50 kg·cm）防水舵机。我选的 7465W 只有 5.8 kg·cm @ 8.4 V——但我的桨板小一个量级（18.5 cm² vs 他们的 55.8 cm²）、桨速小 2–4 倍，估算脚踝峰值力矩 0.4 kg·cm、髋 0.6 kg·cm，余量仍然很大。反过来这提醒我：一旦把桨面放大到他们那个尺度，力矩会从"任何舵机都够"变成真正的瓶颈；D2w73（板加宽到 73 mm）就是往那个方向走的一步。
- **D2w73 的判据要改。** 本文的规律是"推力↑必然伴随力矩↑、能耗↑"。我预期 D2w73 推力 ×1.5，那么按此规律 |M̄y| 和 F̄z/F̄x 会同步变差。所以 D2w73 的取舍判据应该以 F̄z/F̄x 和 |M̄y| 为准，而不是只看净推力——这一条我要写进算例判据表。
- **浮心高于重心。** 作者建议 CB 置于 CG 之上以抑制横摇。我的 M3 船体设计应当据此核对浮心/重心的相对高度。
- **可引用的空白陈述。** 作者写道，基于学习的方法已用于腿式机器人的步态学习与能效优化，"但学习过程中腿式机器人与流体介质的相互作用仍未被探索"。这正是我在考虑的 RL / 最优控制方向所需要的空白陈述，可以直接引用。

## 关联知识

- 阻力型推进（drag-based）与升力型推进（lift-based）的分野，及其与陆上通过性之间的取舍——这是所有腿式两栖机器人的底层折中。
- 尖锐界面浸没边界法（sharp-interface IBM）+ 笛卡尔网格 + 域分解 MPI 并行，作为 overset（重叠网格）之外的另一条处理大位移运动边界的路线；节点分为 fluid / solid / ghost / hybrid 四类的处理方式。
- 三个可复用的无量纲指标：推力系数 CT、功率系数 P̄avg、腿间干涉比 F̄x / 4F̄SL。
- 三种推力生成模式（Trotting / Hindering / Separate）——作为描述"多桨相位关系"的一套现成语言，比"两相/四相"更有物理含义。
- "峰值推力构型只由摆幅决定"这一类构型不变量，可作为检查自己轨迹是否落在合理区间的快速判据。

## 相关研究问题

- [[单腿最优划水轨迹如何定义]]
- [[回程阻力如何通过机构自由度消掉]]
- [[占空比 DUTY 的最优值由什么决定]]
- [[四足相位与整机稳定性之间如何取舍]]
- [[腿间干涉是增益还是损失]]

## 相关论文

- 与 [[Qu 2025 Bioinsp Biomim 20 036012]] 的共同点：同为四足划水、同样关心单腿与整机的关系、同样发现缩短划水相能提高推力（Qu 实测单腿 PP25/33/50% 分别为 0.17/0.15/0.12 N，趋势与本文 DR 一致）。区别：Qu 是实测 + 整机，Wang 是纯 CFD 且无实验校核，量级高出 2–5 倍。两者对"序列步态/短划水相推力更高但稳定性更差"这一点相互印证（Qu：四相比两相快 1.69× 但横摇 4.6×；Wang：对角序的 Mx、Mz 远大于 trot）。
- 与 [[Lin 2024 arXiv 2409 14707]] 的区别与互补：Lin 的腱耦合折叠蹼把开合过渡时间缩短 45–67%、效率从 1.45% 提到 2.86%，处理的正是 Wang 缺席的那个回程自由度。Wang 提供"没有折叠时的基线"，Lin 提供"折叠能带来多少"，而我的工作是把这两者放进同一套 CFD 里定量比较，并进一步把折叠替换为羽化（feathering）。
- 对 [[基于阻力公式与假定 Cd 的简化四足模型]] 的反驳：本文用 F̄x / 4F̄SL ≠ 1（且不单调）直接证明了"整机 = 单腿线性叠加 + 相位移"不成立。

## 下一步行动

- [ ] 在我的结果表里补一列 CT = 2F̄x,avg /(ρŪ²A)，让 V3 / V3c12 / V3trap / 最优 / D2 系列能与本文表 2 同框比较
- [ ] 对 V3trap 补网格无关性（3 套）与时间步无关性（3 套）曲线，按附录 A 的方式呈现
- [ ] 把 V3 → V3trap 的 +32% 拆干净：速度律、T、DUTY 三项各贡献多少（避免重复本文在 DR 上犯的混淆）
- [ ] D2 系列跑完后，用"推力↑必然伴随力矩↑、能耗↑"的规律核对 D2w73，判据用 F̄z/F̄x 与 |M̄y| 而非净推力
- [ ] 整机阶段直接采用本文的步态定义与 F̄x / 4F̄SL 指标，不重做步态序列扫描
- [ ] 核对 M3 船体浮心是否位于重心之上
- [ ] 把 Wang 的"学习过程中腿–流体交互未被探索"一句存入引言素材库，用于 RL 方向的动机陈述

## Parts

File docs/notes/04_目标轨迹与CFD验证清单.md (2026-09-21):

# 04 · 结构无关的目标轨迹（target trajectory）+ 开合时机 + 还缺哪些 CFD

文件：`optimal_trajectory.py`（生成，全部是参数）→ `optimal_trajectory.csv`（每 2 ms：绝对/相对 O2 坐标、速度、桨轴角、开度、准定常示意力、相位）、`optimal_trajectory_events.json`、`fig_optimal_trajectory_storyboard.png`（12 帧分镜）、`optimal_trajectory_anim.mp4`（与你的 leg_anim 同风格 + 底部时间线）
配套：`make_leg_cfd.py` 新增 `--traj optimal_trajectory.csv`（桨按 CSV 轨迹做刚体运动，写 6DoF.dat；gait.json 里带 TAU_OPEN / TAU_CLOSE）；`fold_timing_sweep.py --extra opt=~/run/opt`（合成与扫描）

## 0 直接回答

**文献能不能得出这条轨迹？** 定性能，定量不能。
- 能：形状与顺序——直线向后划、桨面垂直运动、划水一开始就全开、减速段就收、回收相收拢+羽化+尽快返回、过渡越短越好、DUTY 由折叠比定（`03_` §1–2）。这些在麝鼠（Fish 1984）、虾足机器人（Santos 2026）、水甲虫腿（Kwak 2019）、蹼足机器人（Lin 2024、Niu 2026）和准定常理论里是一致的。
- 不能：任何一个"数"。三个原因：
  1. **"最高推力"没有约束是无界的**（推力 ∝ v²，越快越大）。必须先固定舵机速率/力矩（或功率）和可达范围，最优解随约束变。文献的约束（肌肉、别的舵机、别的 Re）都不是你的。
  2. **非定常效应决定了时机的数值**。V3 的 CFD 划水相平均 133 mN，按准定常 C_N = 1.3 只有 ~55–65 mN：起动 2 个弦长内的有效 C_N ≈ 2.3–2.8（涡形成阶段，Kim & Gharib 2011）。所以行程该多长、什么时候收扇（V3 扫出来是划水相 80 % 处）、停顿有没有用，都只能对**你这块 120° 折扇、Re ≈ 10⁴、水线附近**算。
  3. **没有一篇文献是折扇桨 + 腿 + 这个尺度**：Wang/Qu 是刚性狗腿；Lin/Niu 是蹼足但没有 CFD 时序优化；Santos 是虾足（cupping，不是折扇）。

所以下面的轨迹是"**准定常理论 + 你自己 V3 算例扫出的时机 + 文献定性规则**"拼出的**假设**（hypothesis），§4 的 CFD 把它变成设计输入。

## 1 约束（不是结构，是包络）

| 约束 | 取值 | 依据 / 可改 |
|---|---|---|
| 桨头中心峰值速度 v_max | 0.35 m/s | 舵机 215 °/s × r ≈ 95 mm（V1–V3 的峰值髋速率）；`--vmax` |
| 加/减速时间 | 45 ms（7.8 m/s²） | 舵机力矩上限待 C1 核对；`--tramp` |
| 划水直线行程 L_p | 84 mm ≈ 2 弦 | 可达 r ≲ 105 mm；`--lp`（C2 决定该不该更长/更短） |
| 划水线深度（桨头中心） | z = −85 mm（绝对；相对 O2 −89 mm） | 桨竖直时桨根 E 在水线附近、桨尖 −106 mm；`--zp` |
| 回收抬升 | 30 mm | 避开划水尾流，桨头顶离水面 24 mm；`--lift`（C5 决定） |
| 划水后停顿 | 30 ms | Kwak 2019 的 relaxation phase；`--pause`（C3 决定） |
| 开/合过渡 | 60 ms | 现动画的 8 % T；`--tfan`（越短越好，Lin 2024） |
| 桨头 | 现有 120° 扇（42 mm，张开 18.5 cm²；收拢 12 mm；羽化后迎流 5.6 mm） | 换桨重跑 |
| 工况 | 系泊 U = 0 | 巡航另算（C8） |

## 2 目标轨迹（图 `fig_optimal_trajectory_storyboard.png`、动画 `optimal_trajectory_anim.mp4`）

坐标与你的 leg_anim 相同：绝对坐标，O2 = (63.4, 4) mm，WL = −10 mm；CSV 里同时给相对 O2 的固件坐标（+x 前、+z 上）。

路径（绝对坐标，mm）：S (105.4, −85) ──直线向后──▶ E (21.4, −85) ▪停顿▪ ──斜上──▶ R1 (41.4, −55) ──水平──▶ R2 (85.4, −55) ──斜下──▶ S。拐角倒圆 8 mm。回收路径长 114 mm。

**T = 0.684 s（1.46 Hz），DUTY = 0.42**（划水 285 ms + 停顿 30 ms + 回收 369 ms）。

| 事件 | t [ms] | τ | 说明 |
|---|---|---|---|
| 开扇指令 | −45（= 639） | −0.066（0.934） | 回收减速一开始就开；桨在斜下段末尾、前向速度正在降到 0 |
| 反向点 S，划水开始 | 0 | 0 | 开度已 75 % |
| 全开 | +15 | 0.022 | 划水加速段内（v = 0.33 v_max） |
| 匀速 0.35 m/s | 45 → 240 | 0.066 → 0.351 | 桨面垂直 x，全开，最深 |
| **收扇指令** | 240 | 0.351 | = 划水减速开始（V3 扫描：open 在划水相 80 % 处就已不如 closed） |
| 停止 E | 285 | 0.416 | 开度 25 % |
| 全闭 | 300 | 0.438 | 停顿内完成；收拢后绕桨轴转 90° 羽化 |
| 回收开始 | 315 | 0.460 | 斜上，45 ms 加速到 0.35 m/s |
| 到达抬升高度 | 454 | 0.662 | 水平段 |
| 离开水平段 | 546 | 0.796 | 斜下 |
| 回收减速开始 = 开扇 | 639 | 0.934 | 见第一行 |

桨姿态：桨轴始终竖直（桨尖朝下）；划水相桨面 ⟂ x；回收相收拢并绕桨轴转 90°（风向标式羽化），侧视图仍是竖直条，x 向迎流 5.6 mm。

准定常示意（只看相对值）：周期平均 43 mN（划水 114、回收 −9）。真实值要 CFD：V3 的 CFD 比同样的准定常高 ~2 倍。

## 3 从轨迹反推的机构要求

1. **划水段**：84 mm 直线在 O2 下方 89 mm。用摇臂弧代替：r ≈ 95–100 mm、±25°，矢高 ≈ 8 mm，桨面与运动方向夹角 ≤ 25°（cos 损失 < 10 %）——V3 的"行程居中 90°"已经是这个思路，不必做直线机构（C4 会给出弧 vs 直线的差，预计 < 10 %）。
2. **速度律**：舵机要能走梯形（匀速段 + 45 ms 斜坡），不是正弦。固件轨迹插值改成等速分段即可；力矩峰值待 C1 的 M_y。
3. **回收抬升 30 mm**：平行四边形蜷缩已能做到；量多少由 C5 定。
4. **开合必须可控时刻**，不能是"划水结束自动松线"：收扇在减速开始（比划水结束早 45 ms），开扇在回收减速开始（比反向点早 45 ms）。过渡 ≤ 60 ms。→ 主动拉线（舵机/电磁）或与髋摆动机械相位耦合的凸轮。
5. **羽化**：收拢后桨绕自身轴自由转 90°（被动铰 + 限位，像风向标），或把收拢宽做到 ≤ 6 mm。这一项让回收阻力从 12 mm 宽变 5.6 mm，a_eff 从 ≈ 0.22 再降一半。
6. **速率/力矩预算**：v_max 0.35 m/s ↔ 215 °/s；加速 7.8 m/s² 时附加质量项可能超过现有舵机峰值力矩（V1/V3 的 |M_y| ≈ 20 mN·m）——C1 之后再定 `--tramp`。

## 4 还需要哪些 CFD（每个"算例"= open + closed 两次计算，除非注明；两态合成用 gait.json 的 TAU_OPEN/TAU_CLOSE）

| 编号 | 回答什么 | 设置（都用 `--traj`，改 `optimal_trajectory.py` 的参数） | 计算次数 | 判据 |
|---|---|---|---|---|
| **C6 真实收拢 + 羽化** | a_eff 到底多少 → DUTY* 与回收速度 | closed：收拢 12 mm（`CLOSED_W=0.012`）；closed：羽化 5.6 mm（`CLOSED_W=0.006`） | 2（只 closed） | 回收相平均 −F_x；a = F_rec/F_pw ÷ (v_r/v_p)² |
| **C1 速度律** | 匀速划水比余弦多多少；舵机力矩够不够 | V3 几何、同 v_max：梯形（45 ms）vs 余弦 | 2 | 划水相冲量 ∫F_x dt（准定常理论 +60–70 %）、M_y 峰值 |
| **C2 行程长度** | 涡形成阶段有多长——行程该 1.5 / 2 / 3 弦 | 直线平动，L_p = 63 / 84 / 126 mm，同 v_max，T 随之变 | 4（84 mm 与 C1 共用） | 周期平均推力（不是单次冲量） |
| C4 直线 vs 圆弧 | 值不值得做直线机构 | 同 L、同 v：平动 vs r = 95 mm 摇臂弧 | 2 | 周期平均推力差 < 10 % 就用弧 |
| C3 停顿 | relaxation phase 有没有用 | 停顿 0 / 30 / 60 ms，其余不变 | 4 | 周期平均推力 & 停止涡（看 Q 判据切片） |
| C5 回收抬升 | 避尾流值不值多走 30 mm | lift 0 / 30 mm（羽化） | 2（只 closed） | 回收相阻力 vs 多出的时间 |
| C7 过渡本身 | 收/开扇过程的损失有多大 | 半开 60° 静态第三态 1 次 | 1 | 三态合成 vs 两态合成的差 |
| C8 前进速度 | 巡航时开合窗口怎么缩 | U = 0.1 / 0.2 m/s | 4 | F̄_x(U)、开扇窗口 v > U |
| C9 自由面 | 只在回收贴近水面时需要 | interFoam，同轨迹 | 2 | 与单相差 > 10 % 才需要 |

最小决定集（能定下设计输入）：**C6 + C1 + C2 = 8 次计算**（约 4 个 V3 算例的工作量）；完整 23 次。顺序按表格从上到下。

## 5 怎么跑

```bash
cd /mnt/c/Users/L/Desktop/openfoam/robot_real/leg_dynamics/results/papers && python3 optimal_trajectory.py          # 改参数：--vmax --tramp --lp --zp --lift --pause --tfan --feather
cd /mnt/c/Users/L/Desktop/openfoam/robot_real/leg_dynamics
python3 make_leg_cfd.py --case ~/run/opt_open   --fan open   --U 0 --traj results/papers/optimal_trajectory.csv
python3 make_leg_cfd.py --case ~/run/opt_closed --fan closed --U 0 --traj results/papers/optimal_trajectory.csv
# 跑完把 force_open/closed.dat、moment_*.dat、gait_*.json 收到一个目录（同 results_verify/V3 的做法），然后
python3 results/papers/fold_timing_sweep.py --extra opt=~/run/opt_collect               # 合成 + 再扫一次开合时刻
```
注意：轨迹模式下桨 STL 仍含 50 mm 细杆，桨根 E 在水线附近（单相计算不管水面，影响可忽略）；`--leg` 不能与 `--traj` 同用。

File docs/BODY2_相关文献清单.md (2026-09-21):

# BODY2 相关文献清单（2026-09-10 检索）

按**对你当前工作的用处**分组，不按学科分。每条给了链接、是否开放获取（OA），以及"用在哪一步"。
已有的两篇（Fish 2020 *The dog paddle*、Cui 2026 arXiv 2603.04073 ACPPO-PID）不再重复列出。

---

## 一、必读：直接支撑你已经做完的结论

### 1. Fish (1984)《Mechanics, power output and efficiency of the swimming muskrat》
*Journal of Experimental Biology* 110: 183–201 · [作者主页免费 PDF](https://www.wcupa.edu/sciences-mathematics/biology/fFish/documents/1984JEBMuskratMechanics.pdf) · **OA**

**这是你仿生对象（muskrat 麝鼠 / 水老鼠）本身的定量测量，且数字和 V3 惊人吻合。**已核对原文页码：
- 划水相 0.18 ± 0.01 s，回收相 0.22 ± 0.01 s → **占空比 0.45**（p. 191）——与你 CFD 选出的 V3（DUTY = 0.45）完全相同，纯属独立佐证。
- 划频在 0.2–0.75 m/s 全速度段**恒定在 2.5 ± 0.06 Hz**，动物靠**加大摆幅**而不是提高频率来提速（p. 190）。这与你"提高速率"的路线相反，值得在报告里讨论。
- 回收相桨的阻力**只有划水相的 33 %**（p. 194），靠趾收拢 + 足旋后把迎流面积减少 **55.5 %**（p. 194）——你的扇形脚蹼开合比是 20.0/13.3 = 1.5×（面积减少 33 %），**比麝鼠弱不少**，说明收拢宽度 CLOSED_W 还有优化空间。
- 回收相耗功是划水相的 20–39 %（p. 194）；最大机械效率 0.33（p. 197–198）。

用途：写作时的生物学基准（Kap. 2 仿生依据）；论证 DUTY 0.45 的选择；论证 CLOSED_W 该做小。

### 2. Csillag & Ribak (2025)《Underwater paddling kinematics and hydrodynamics in a surface swimming duck versus a diving duck》
*J. Exp. Biol.* 228(9): jeb249274 · [DOI 10.1242/jeb.249274](https://doi.org/10.1242/jeb.249274) · **OA**

**直接支撑我们上周关于 F_z（垂向力，Vertikalkraft）的讨论。**水面型（鸳鸯）的蹼产生**向上**的力，与自身浮力对抗；潜水型（潜鸭）低头约 16°、行程弧更小，把足力指向**向下**，作者证明这才是水平游动的高效运动学。也就是说：垂向分量的方向和大小是被行程平面姿态决定的设计变量，不是副产品。
另注：两种鸭子的划水相都**短于**回收相，与你的"短回收更好"相反 —— 这个矛盾值得在报告里明说（动物在省代谢能和控浮，机器人不需要）。

用途：F_z 一节的文献支撑；V3 降中心角（把力矢量倾角从 20° 压到 8°）的生物学对照。

### 3. Ribak & Gurka (2023)《The hydrodynamic performance of duck feet for submerged swimming resembles oars rather than delta-wings》
*Scientific Reports* 13: 16217 · [DOI 10.1038/s41598-023-42784-w](https://doi.org/10.1038/s41598-023-42784-w) · **OA**

蹼足在水动力上是**桨（drag-based oar）而不是三角翼**，流场里没有前缘涡升力。C_D 从 10° 攻角的约 0.25 单调升到 75° 以上的约 1.5，法向力峰值在 55° 攻角附近，30°–140° 之间力都很稳定。

用途：**这是你准定常叶素模型（quasi-steady blade element）最直接的合法性依据**——用纯阻力式建模是对的；也说明攻角在很宽范围内力都差不多，所以桨的俯仰精度要求不高。

---

## 二、直接可比的机器人：你的 benchmark 和竞争工作

### 4. Qu, Cai, Fish, Li, Chen, Zhong 等 (2025)《Amphibious robotic dog: design, paddling gait planning, and experimental characterization》
*Bioinspiration & Biomimetics* 20(3): 036012 · [DOI 10.1088/1748-3190/adcd1b](https://doi.org/10.1088/1748-3190/adcd1b) · 需订阅（TUM 图书馆有）

**平台最接近、且 Frank Fish 是共同作者。**双关节腿四足，三种划水步态：两种狗式（**划水相占 25 % 与 33 %**，侧对角序列）和一种类小跑（**50 %**）。结论：侧序列步态推力/速度更好，类小跑更稳。水中最高 0.576 km/h（0.16 m/s），陆上 1.26 km/h。还专门设计了重心–浮心关系来保证浮态稳定。

用途：**你的 V1/V2/V3 占空比对比的直接对照组**；速度指标的 benchmark；浮态稳定性的论证方式。

### 5. Wang, Cai, Xie, Zhu, Li, Chen (2025)《A Computational Study on the Hydrodynamics of Bio-Inspired Quadrupedal Paddling》
*Biomimetics* 10(3): 148 · [DOI 10.3390/biomimetics10030148](https://doi.org/10.3390/biomimetics10030148) · **OA**

**参数扫描和你几乎一模一样**：初始摆角（60/70/80°）× 摆幅（20/30/40°）× 划水相占比（50 %/33 %/25 %）× 三种步态序列（小跑/对角/侧序列）。发现三种推力生成模式（Trotting / Hindering / Separate），其中 Hindering = 前一条腿刚离开划水相的阻力抵消后一条腿的推力。**对角与侧序列产生的水动力矩远大于小跑**；推力越大，力矩和能耗同步上升。

用途：（a）你整机 4 相 vs 2 相步态选择的直接依据；（b）方法学对照——它用**浸没边界法（immersed boundary）、无自由面**，而你用 overset + VOF **带自由面**，正好是你的差异化卖点；（c)"低中心角能不能白拿"这个问题它给了警告：推力上去，力矩也上去。

### 6. Han 等 (2025)《Learn to Swim: Data-Driven LSTM Hydrodynamic Model for Quadruped Robot Gait Optimization》
ICRA 2025 · [arXiv:2505.03146](https://arxiv.org/abs/2505.03146) · **OA**

西湖大学（与你已有的 Cui 2026 同组）。用约 300 万点水槽/拖曳水池测力数据训练 LSTM 代理模型（FED-LSTM），再用 **NSGA-II** 对髋最小角、膝最大角、频率、腿间相位做多目标步态优化。明确论证经验/准定常公式低估非定常力。

用途：**你"标定后的准定常模型 + 少量 CFD 验证"路线的对照方法**。你可以说：他们用 3 M 实测点换一个黑箱，你用 6 个 CFD 算例标定一个可解释模型，偏差 ±16 %。这是论文里很有力的一段。

### 7. Lin, Guo, Badri-Spröwitz (2024)《Bird-inspired tendon coupling improves paddling efficiency by shortening phase transition times》
[arXiv:2409.14707](https://arxiv.org/abs/2409.14707) · **OA**（已核对全文数据）

**和你的线驱动扇形脚蹼是同一个机构问题。**蹼由三块三角片经尼龙布 + Kevlar 绳连接、带硬限位，回收时**自折叠**，划水时由伸肌腱拉开。核心发现：效率提升**不是来自面积比，而是来自把折叠↔展开的过渡时间缩短 45–67 %**。带全套腱：净推力 1.72 ± 0.06 N、推进效率 2.86 ± 0.12 %；无伸肌腱：0.86 ± 0.09 N、1.45 ± 0.15 %；被动桨基线只有 0.84 ± 0.09 %。

用途：**你的 FAN_CLOSE / 8 % T 过渡时间可能比 FAN_DEG 更值得优化**——这是一个你还没做过的敏感性方向，而且不用改机构，只改线的预紧和松线相位。

---

## 三、脚蹼/桨的设计与建模（变面积、被动折叠）

### 8. Hu 等 (2024)《Design and Reality-Based Modeling Optimization of a Flexible Passive Joint Paddle for Swimming Robots》
*Biomimetics* 9(1): 56 · [DOI 10.3390/biomimetics9010056](https://doi.org/10.3390/biomimetics9010056) · **OA**

方法学上最贴近你的一篇：刚性 PA66 分片 + 硅胶铰链 + 机械限位，划水时限位顶住保持共面（最大投影面积），回收时自动屈曲卸阻力；**单舵机对称指令**，不对称完全来自铰链非线性。建模用**伪刚体模型 + 叶素理论**，再用高速相机实验标定水动力系数，力误差 0.51 %。

用途：你"准定常叶素 + CFD 标定"链条的可引用先例；如果以后要做柔性桨，这是模板。

### 9. Chen, Wang, Tu, Wang (2022)《Dynamic modeling and experiment of hind leg swimming of beaver-like underwater robot》
*Mechanical Sciences* 13: 831 · [DOI 10.5194/ms-13-831-2022](https://doi.org/10.5194/ms-13-831-2022) · **OA（全文免费 PDF）**

"刚–液融合"单腿模型：可弯曲蹼足上的积分水动力（叶素式）耦合大腿/小腿的 Newton–Euler 刚体动力学，输出推进力与升力；用 Fluent 仿真 + 单腿水下游动实验验证，比较仿生/加大幅度/减小幅度三条轨迹。

用途：**你单腿 CFD + 解析模型验证链条的现成模板**，而且全文免费，写方法章时可直接对标结构。同组的 Chen 等 (2021) *Ocean Engineering* 234: 109179（[DOI](https://doi.org/10.1016/j.oceaneng.2021.109179)，需订阅）给了可弯曲蹼足的诱导速度修正和"划水后停顿降阻"的做法。

### 10. Kim & Gharib (2011)《Characteristics of vortex formation and thrust performance in drag-based paddling propulsion》
*J. Exp. Biol.* 214(13): 2283–2291 · [DOI 10.1242/jeb.050716](https://doi.org/10.1242/jeb.050716) · 需订阅

阻力式划水的奠基性实验（旋转平板 + 3D PIV，Re ≈ 140–19 720）。三个对你有用的结论：涡强度的**时间变化率**而非幅值决定推力；**三角形（delta / 扇形）桨产生的展向流远强于矩形桨**——正好对应你 120° 扇形；**柔性桨在快速加速段削平推力峰值但不损失总冲量**。

用途：扇形几何的正当性；如果 V1/V3 的舵机峰值力矩（20 mN·m）成为瓶颈，柔性桨膜是一条"降峰不降冲量"的出路。

### 11. Herrera-Amaya & Byron (2024)《Propulsive efficiency of spatiotemporally asymmetric oscillating appendages at intermediate Reynolds numbers》
*Bioinspiration & Biomimetics* 19: 066004 · [DOI 10.1088/1748-3190/ad7abf](https://doi.org/10.1088/1748-3190/ad7abf) · 需订阅

**和你的核心变量最贴近的一篇**：用机器人桨分离"空间不对称（面积变化）"与"时间不对称（划水快/回收慢）"各自的贡献，并提出一个脱离整机动力学的"integrated efficiency"指标（正好适合你的单腿孤立算例）。还发现**弯曲柔性桨比直桨效率高，且不用复杂控制就能产生空间不对称**。
同组的 Herrera-Amaya 等 (2021) *ICB* 61(5): 1579（[DOI 10.1093/icb/icab179](https://doi.org/10.1093/icb/icab179)）给出理论骨架：**Re 越高，空间不对称越不重要、时间不对称越重要**——先算你桨的 Re（你的桨头 Re ≈ 1.1×10⁴），再决定该优化 CLOSED_W 还是占空比。

### 12. Blake (1981)《Influence of pectoral fin shape on thrust and drag in labriform locomotion》
*Journal of Zoology* 194(1): 53–66 · [DOI 10.1111/j.1469-7998.1981.tb04578.x](https://doi.org/10.1111/j.1469-7998.1981.tb04578.x) · 需订阅

阻力式划水的鱼倾向于**三角形（扇形）而非方形**胸鳍，尽管方形鳍的压差阻力实测低约 14 %。配合 Blake (1980) *JEB* 85: 337（[免费 PDF](https://journals.biologists.com/jeb/article-pdf/85/1/337/3193575/jexbio_85_1_337.pdf)）——最早明确指出划水式推进必须把**回收相算进效率**，不能只看划水相。

用途：扇形几何 + "整周期效率"这两个立论的经典出处。

---

## 四、CFD 方法学与船体（写方法章 / V&V 用）

### 13. Chen 等 (2019)《Application of an overset mesh based numerical wave tank for modelling realistic free-surface hydrodynamic problems》
*Ocean Engineering* 176: 97–117 · [DOI 10.1016/j.oceaneng.2019.02.001](https://doi.org/10.1016/j.oceaneng.2019.02.001) · 需订阅

OpenFOAM overset + VOF 的验证集合：波中浮体、**入水（water entry）**、WEC 升沉衰减。明确论证大幅运动下 overset 优于网格变形（mesh morphing）——正是你桨穿越水线时需要的论据。

### 14. Windt, Davidson, Chandar, Faedo, Ringwood (2020)《Evaluation of the overset grid method ... in OpenFOAM numerical wave tanks》
*J. Ocean Eng. Mar. Energy* 6(1): 55–70 · [DOI 10.1007/s40722-019-00156-5](https://doi.org/10.1007/s40722-019-00156-5)

五个难度递增的算例对比 overset 与 morphing：运动幅度大到一定程度**morphing 直接崩，overset 活下来**，代价是约 2× 运行时间。你被问"为什么用 overset、为什么这么慢"时的标准答案。

另可参考 Kozelkov 等 (2026) *Fluids* 11(6): 138（[DOI 10.3390/fluids11060138](https://doi.org/10.3390/fluids11060138)，**OA**）：两种方法在阻力系数上差约 0.5 %，3D 情形 overset 反而便宜约 10 %。

### 15. ITTC 推荐规程
- **7.5-03-02-04 Practical Guidelines for Ship CFD**（2024 修订）· [免费 PDF](https://www.ittc.info/media/11960/75-03-02-04.pdf)：网格、y⁺、自由面加密、计算域尺寸、时间离散阶数的可引用出处。
- **7.5-02-02-01 Resistance Test**（2011）· [免费 PDF](https://ittc.info/media/1217/75-02-02-01.pdf)：明确规程**预设了湍流激励**、模型"尽可能大"、修正就是为了**避免层流**。

用途：**这正是你需要的"ITTC-57 摩擦线在 Re ≈ 3×10⁴ 不适用"的正式依据**——不是你算错了，是那条线本来就不为这个雷诺数设计。配合 Terziev, Tezdogan, Incecik (2022)《Scale effects and full-scale ship hydrodynamics: a review》*Ocean Engineering* 245: 110496（[作者版 PDF](https://momchil-terziev.github.io/files/Draft_1.pdf)，**OA**）讲外推的不确定性。船体章里直接报 CFD 力、把 ITTC 对比降为"仅供参照"，是站得住的做法。

### 16. Eça & Hoekstra (2014)《A procedure for the estimation of the numerical uncertainty of CFD calculations based on grid refinement studies》
*J. Comput. Phys.* 262: 104–130 · [DOI 10.1016/j.jcp.2014.01.006](https://doi.org/10.1016/j.jcp.2014.01.006) · 需订阅

最小二乘 / 观测阶方法，专为**网格加密不均匀、观测阶不听话**的情况设计——snappyHexMesh + overset 就是这种情况，比裸用 GCI 合适。结构上配 Stern, Wilson, Coleman, Paterson (2001) *ASME JFE* 123(4): 793（[作者 PDF](http://servidor.demec.ufpr.br/CFD/bibliografia/erros_numericos/Stern_et_al_2001.pdf)）。

### 17. Picardi, Astolfi, Chatzievangelou, Aguzzi, Calisti (2023)《Underwater legged robotics: review and perspectives》
*Bioinspiration & Biomimetics* 18 · [DOI 10.1088/1748-3190/acc0bb](https://doi.org/10.1088/1748-3190/acc0bb) · OA (CC BY-NC-ND)

水下足式机器人的综述，把开放问题按环境交互/感知驱动/建模控制/自主性归类，并与螺旋桨式 ROV/AUV 对比。引言里"为什么用腿划水而不是螺旋桨"的标准出处。

---

## 五、值得知道但优先级较低

- **Baines 等 (2022)《Multi-environment robotic transitions through adaptive morphogenesis》** *Nature* 610: 283（[DOI](https://doi.org/10.1038/s41586-022-05188-w)）+ Baines 等 (2020) *Bioinsp. Biomim.* 15（[DOI](https://doi.org/10.1088/1748-3190/ab68e8)）：变形肢（海龟鳍↔陆龟腿），"一条腿两种水动力状态"的奠基工作。
- **Wang, Pancheri, Lueth, Sun (2025)《DuckyDog: An Erect Amphibious Robot with Variable-Stiffness Legs and Passive Fins》** *Advanced Intelligent Systems* 7（[DOI 10.1002/aisy.202500267](https://doi.org/10.1002/aisy.202500267)，**OA**）：**TUM MiMed（Lueth / Sun）自家工作**，腱驱动 + 被动鳍，水中 0.30 BL/s。校内引用，答辩时容易被问到。
- **Ding 等 (2025)《Diving-Beetle-Inspired Paddling Propulsion Robot》** *Biomimetics* 10(3): 182（[DOI](https://doi.org/10.3390/biomimetics10030182)，**OA**）：不完全齿轮 + 扭簧做出"快划慢回"，被动足在回收时折叠。纯机械实现不对称的思路。
- **Qi 等 (2021)《Observation and analysis of diving beetle movements while swimming》** *Sci. Rep.* 11: 16581（[DOI](https://doi.org/10.1038/s41598-021-96158-1)，**OA**）：龙虱划水相只占 30–47 %，回收时跗节旋转 + 刚毛折叠几乎消除阻力；后腿同步比交替更高效。
- **Walker & Westneat (2000)** *Proc. R. Soc. B* 267: 1875（[PMC1690750](https://www.ncbi.nlm.nih.gov/pmc/articles/PMC1690750/)，**OA**）与 **Fish (1996)** *Am. Zool.* 36(6): 628（[DOI](https://doi.org/10.1093/icb/36.6.628)）：划水（rowing）效率上限约 33 %，摆动翼（flapping）可超 80 %。诚实交代你这一类推进方式的天花板，然后说明增益只能从占空比、回收阻力、力方向对齐里挖——正是你做的三件事。
- **Ghazali, Abdul Satar, Rahiman (2024)《Unmanned surface vehicles: From a hull design perspective》** *Ocean Engineering* 312: 118977（[DOI](https://doi.org/10.1016/j.oceaneng.2024.118977)）：USV 船型综述，你船体比选课题的上位框架。

---

## 六、检索中发现的两个空白（可能是你的贡献点）

1. **反复穿越水线的附体（每周期入水 + 出水）的 overset 力验证**：Chen 2019 只覆盖一次性入水；没有找到对"附在运动船体上、周期性进出水的附体"做力验证的工作。你的单腿 + 整机算例正好填这个缝。
2. **ITTC 摩擦线在 Re ≈ 3×10⁴ 是否成立**：没有论文直接测过。文献只说明该线预设湍流激励、外推不确定性大。你的"层流 vs k-ω SST 对比"在这个雷诺数上是有正当动机的。

另外，第 4、5 两篇（Qu 2025、Wang 2025）都在做占空比扫描，但**都没有加垂向力约束**，而 Cui 2026 加了却没做形状/中心角。你的 "F̄_z/F̄_x = 0.28、两对腿叠加升沉激励最低" 是这三者之间的空隙。

---

*检索日期 2026-09-10。带 **OA** 的可直接下载；其余 TUM 图书馆（eaccess.ub.tum.de）有订阅。BibTeX 见同目录 `BODY2_refs.bib`。*

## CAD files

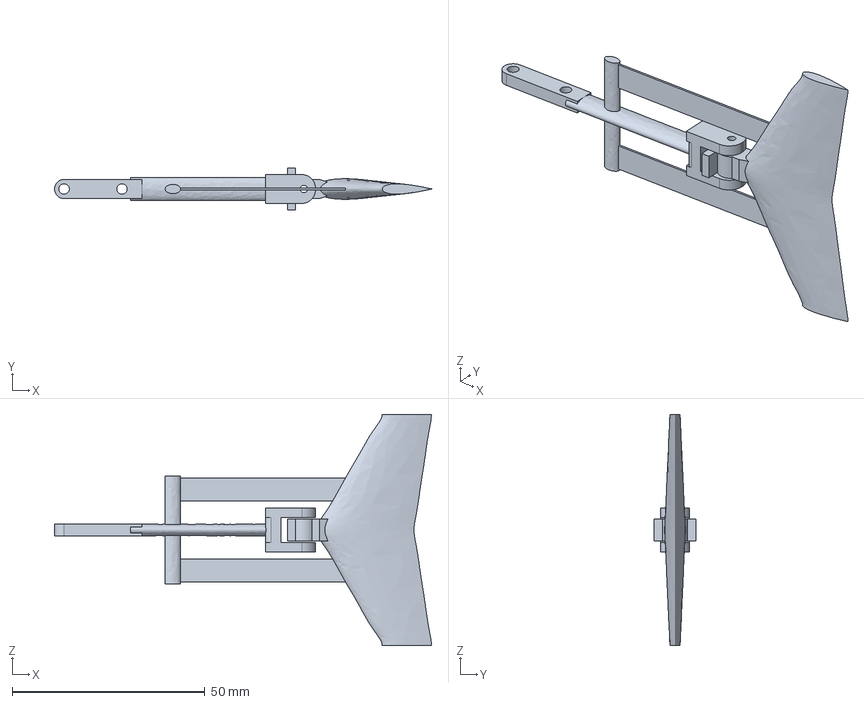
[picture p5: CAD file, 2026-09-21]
cad/fluke_straight_A2.step
97.8 x 11.0 x 60.0 mm

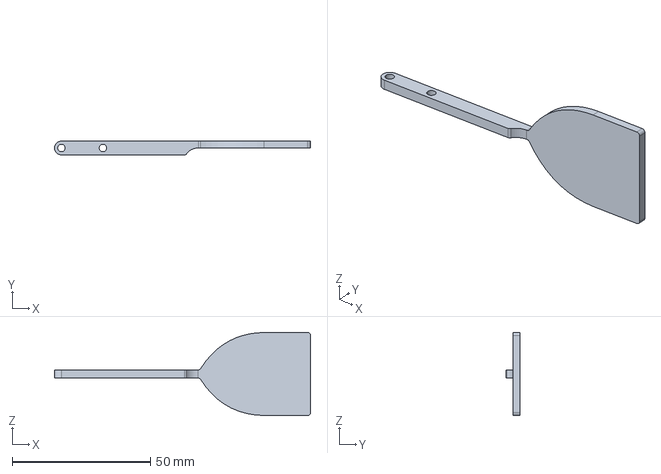
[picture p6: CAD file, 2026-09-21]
cad/fan_foot_orig.step
92.5 x 5.00 x 30.0 mm

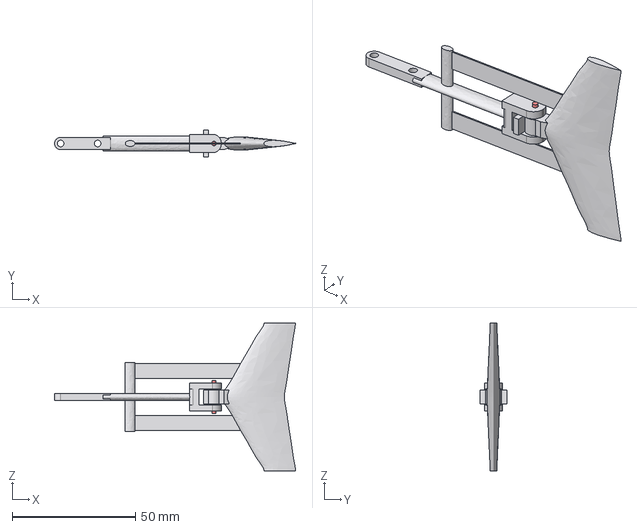
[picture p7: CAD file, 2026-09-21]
cad/fluke_straight_A2_with_pin.step
97.8 x 11.0 x 60.0 mm
fluke_straight_A2
pin_filament_1.75

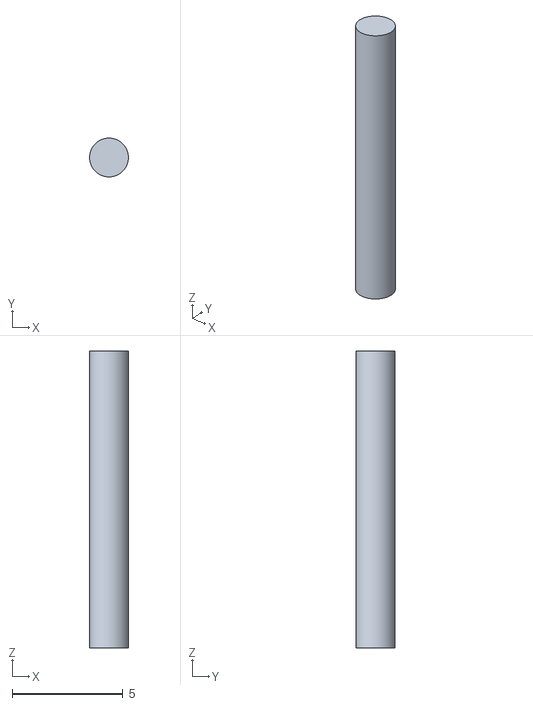
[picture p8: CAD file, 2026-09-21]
cad/pin_1p75.stl
1.75 x 1.75 x 13.4

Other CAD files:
cad/fluke_straight_A2.stl

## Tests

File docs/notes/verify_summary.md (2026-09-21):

# 步态验证算例 vs 行程模型

| 方案 | 步态 | 状态 | CFD F̄_x [mN] | 模型 F̄_x | 偏差 | CFD F̄_z | 模型 F̄_z | |M_y| 峰 [mN·m] | 模型 |M| | P̄ [mW] | 划水相 / 回收相贡献 [mN] | F̄_x 相对现步态 |
|---|---|---|---|---|---|---|---|---|---|---|---|---|
| current | 现步态（T 1.25, 60°, 136→76°, DUTY 0.5, 快蜷缩） | composite，第 3 周期 | **23.4** | 21.0 | +12 % | 14.1 | 12.1 | 8.1 | 9.0 | 6.7 | +29.4 / -6.0 | — |
| V1 | V1 前沿点（T 0.89, 60°, 135→75°, DUTY 0.49, 慢蜷缩 0.45 s） | composite，第 3 周期 | **51.2** | 47.7 | +7 % | 26.8 | 23.3 | 20.5 | 18.5 | 18.0 | +64.5 / -13.4 | +118 % |
| V2 | V2 狗式占空比（T 1.25, 60°, 136→76°, DUTY 0.35, 慢蜷缩 0.81 s） | composite，第 3 周期 | **34.2** | 36.5 | -6 % | 16.8 | 16.7 | 16.6 | 18.5 | 9.9 | +40.4 / -6.2 | +46 % |
| V3 | V3 低中心角（T 0.81, 50°, 120→70°, DUTY 0.45, 慢蜷缩 0.45 s） | composite，第 3 周期 | **49.3** | 42.6 | +16 % | 13.7 | 13.0 | 19.3 | 17.9 | 16.2 | +60.0 / -10.7 | +110 % |
| V3c06 | V3c06 | composite，第 3 周期 | **58.6** | — | — | 9.1 | — | 19.3 | — | 13.1 | +60.0 / -1.4 | +150 % |
| V3c12 | V3c12 | composite，第 3 周期 | **56.7** | — | — | 9.9 | — | 19.3 | — | 13.7 | +60.0 / -3.2 | +142 % |
| V3trap | V3trap | composite，第 3 周期 | **75.0** | — | — | 13.9 | — | 35.6 | — | 20.8 | +79.5 / -4.4 | +220 % |

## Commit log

2026-09-21 A2 fluke leg: CAD, sculling FSI, firmware trajectory, CFD tooling, notes
    [fan_foot_orig.step, fluke_AR4_t0.5_s35_planform_mm.csv, fluke_AR4_t0.5_s35_section_NACA0021.csv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]
2026-09-21 Flatten directory layout
    [fan_foot_orig.step, fluke_AR4_t0.5_s35_planform_mm.csv, fluke_AR4_t0.5_s35_section_NACA0021.csv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]
